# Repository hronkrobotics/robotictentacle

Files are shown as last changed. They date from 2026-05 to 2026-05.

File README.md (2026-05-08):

# robotictentacle

2-DOF robotic tentacle powered by dual 12V geared hobby motors, an L298N motor driver, and an ESP32-C3 Super Mini. Features joystick control and dual 3D-printed capstan drives for tendon actuation. Uses standard thread for proof-of-concept, with support for stronger nylon or cable-based tendons.


## Project Status

This project is currently a **proof of concept**. It demonstrates a low-cost tendon-driven robotic tentacle mechanism using hobby motors, 3D-printed capstan drives, and an ESP32-C3 controller.

The current version is not intended as a finished functional robotic manipulator. The long-term goal is to improve the mechanical design, tendon routing, materials, and control system so the concept can be used in more practical robotic systems, such as:

- Soft robotic grippers
- Tendon-driven manipulators
- Biomimetic robotic arms
- Educational robotics demos
- Low-cost actuation experiments

## System Overview

The tentacle uses a flexible PTFE tube as the central spine. 3D-printed discs are spaced along the tube to create the tentacle body. Threads are routed through aligned holes in the discs and wrapped around two 3D-printed capstans. Each capstan is driven by a 12V geared DC hobby motor.

The motors are controlled by an L298N H-bridge motor driver, which is connected to an ESP32-C3 Super Mini. A joystick provides manual control over the two axes of motion.

## System Breakdown

```mermaid
flowchart TD
    A[12V 3A Power Supply] --> B[L298N Motor Driver]
    B --> C[12V DC Gear Motor 1]
    B --> D[12V DC Gear Motor 2]

    E[ESP32-C3 Super Mini] --> B
    F[Joystick Module] --> E

    C --> G[3D Printed Capstan Drive 1]
    D --> H[3D Printed Capstan Drive 2]

    G --> I[Tendon / Thread Routing]
    H --> I

    I --> J[PTFE Tube Core]
    J --> K[3D Printed Tentacle Discs]
    K --> L[2-DOF Robotic Tentacle]

    M[Wooden Base] --> B
    M --> E
    M --> F
    M --> C
    M --> D
    M --> L
```

## Bill of Materials

| Item | Quantity | Notes |
|---|---:|---|
| ESP32-C3 Super Mini | 1 | Main microcontroller |
| L298N motor driver | 1 | Dual H-bridge motor driver |
| 12V DC geared hobby motors | 2 | Used to drive the capstans |
| 12V 3A power supply | 1 | Main motor power supply |
| Analog joystick module | 1 | Used for manual control |
| Breadboard | 1 | For prototyping connections |
| Jumper wires / hookup wires | As needed | Signal and power wiring |
| Wooden baseboard | 1 | Mounting platform for the full assembly |
| PTFE tube | 1 length | Main flexible core of the tentacle |
| 3D printed tentacle discs | Multiple | Sorted by size and placed along the PTFE tube |
| 3D printed capstan drives | 2 | One for each motion axis |
| Thread | As needed | Proof-of-concept tendon material |
| Needle | 1 | Used to route thread through the discs |
| PLA filament | As needed | Used for 3D printed parts |
| Hot glue or super glue | As needed | Used to secure discs and tendons |
| Solder | As needed | For electrical connections if needed |

## Required Tools

| Tool | Purpose |
|---|---|
| 3D printer | Printing discs, capstans, and mounts |
| Soldering iron | Securing wires and electrical connections |
| Hot glue gun | Attaching parts and securing tendons |
| Screwdriver | Mounting motors and hardware |
| Wire stripper / cutter | Preparing wires |

## 3D Printing Settings

The prototype parts were printed using standard PLA settings.

Recommended starting settings:

| Setting | Value |
|---|---|
| Material | PLA |
| Infill | 25% gyroid |
| Layer height | 0.2 mm |
| Walls | 2-3 |
| Supports | As needed depending on part orientation |

These settings are not strict. The parts do not require extremely high strength, but the capstans and base mounts should be sturdy enough to avoid snapping under tendon tension.

## Mechanical Assembly

### 1. Prepare the Base

Start with a wooden baseboard large enough to hold:

- The two motors
- The L298N motor driver
- The ESP32-C3 Super Mini
- The joystick module
- The breadboard or wiring area
- The tentacle assembly

Mount the two 12V geared DC motors onto the base. Make sure the motor shafts are accessible and aligned with where the capstan drives will sit.

### 2. Prepare the PTFE Core

Cut the PTFE tube to the desired tentacle length. This tube acts as the main flexible spine of the robot.

The PTFE tube is the core of the build. The 3D-printed discs slide onto it, and the tendon threads run along the outside through aligned holes in the discs.

### 3. Sort the Tentacle Discs

Print all tentacle discs and sort them in order of size.

The discs should be installed along the PTFE tube with consistent spacing. A spacing of around **5-10 mm** between discs is recommended.

Smaller spacing can create a more continuous and dexterous tentacle shape, while larger spacing makes assembly easier and reduces the number of printed parts required.

### 4. Install the Discs

Slide the first disc onto the PTFE tube. Add hot glue or super glue around the contact area to secure it in place.

Continue adding discs one by one.

Important: make sure the tendon holes in every disc are aligned. If the holes are not aligned, the tendons will twist or bind later during assembly.

Recommended process:

1. Add one disc to the PTFE tube.
2. Align the four tendon holes.
3. Apply hot glue or super glue.
4. Add the next disc with the same spacing.
5. Repeat until the tentacle body is complete.

### 5. Prepare the Capstan Drives

Print two capstan drives: one for each axis of motion.

Each capstan controls one pair of opposing tendon directions.

For each capstan:

1. Take one end of the thread.
2. Wrap it around one side of the capstan about 5 times.
3. Feed the thread through the center hole or anchor point.
4. Secure it with a knot, hot glue, or both.
5. Repeat for the other side of the capstan if using opposing tendon pulls.

The goal is for the capstan to wind one side of the tendon while releasing the other side.

### 6. Route the Tendons

Use a needle to route the thread through the holes in the tentacle discs.

Route the tendons through the full length of the tentacle and back toward the motor/capstan area.

Tips:

- Route the upper axis first to avoid access issues later.
- Keep the threads as straight as possible.
- Avoid crossing or twisting tendons.
- Make sure each tendon path passes through the matching aligned hole in every disc.
- Leave extra thread length for tensioning and adjustment.

This prototype uses regular thread as a proof of concept. For future versions, the thread can be replaced with stronger materials such as nylon string, braided fishing line, cable, or other tendon materials.

### 7. Mount the Tentacle Assembly

Mount the tentacle base to the wooden board. The tentacle should start upright in its neutral position.

Make sure the tendons can travel freely from the tentacle body to the capstans without rubbing sharply against the base or hardware.

### 8. Mount Electronics

Mount the following onto the wooden baseboard:

- ESP32-C3 Super Mini
- L298N motor driver
- Breadboard
- Joystick module
- Power input wiring

Keep motor power wiring separated from signal wiring where possible to reduce electrical noise.

## Wiring

### L298N to ESP32-C3 Super Mini

| L298N Pin | ESP32-C3 Super Mini Pin | Purpose |
|---|---|---|
| IN1 | GPIO4 | Motor A direction control |
| IN2 | GPIO5 | Motor A direction control |
| IN3 | GPIO6 | Motor B direction control |
| IN4 | GPIO7 | Motor B direction control |
| ENA | GPIO10 | Motor A PWM speed control |
| ENB | GPIO3 | Motor B PWM speed control |
| GND | GND | Common ground |

### Joystick to ESP32-C3 Super Mini

| Joystick Pin | ESP32-C3 Super Mini Pin | Purpose |
|---|---|---|
| VRx | GPIO0 | X-axis analog input |
| VRy | GPIO1 | Y-axis analog input |
| SW | GPIO20 | Joystick button input |
| VCC | 3V3 | Joystick power |
| GND | GND | Ground |

Do not power the joystick from 5V. The ESP32-C3 uses 3.3V logic and its analog inputs should not receive 5V.

### Motors to L298N

| Motor | L298N Output |
|---|---|
| Motor A | OUT1 and OUT2 |
| Motor B | OUT3 and OUT4 |

### Power Wiring

| Power Connection | Destination |
|---|---|
| 12V power supply positive | L298N 12V input |
| 12V power supply negative | L298N GND |
| ESP32-C3 GND | L298N GND |

Use a common ground between the ESP32-C3 and the L298N. The ESP32-C3 can be powered separately over USB during development.

Do not power the ESP32-C3 directly from the L298N 5V output unless the regulator behavior has been verified. Motor drivers can introduce noise and voltage dips that may reset the microcontroller.

## Control Mapping

| Joystick Direction | Tentacle Action |
|---|---|
| Left / Right | Axis 1 movement |
| Forward / Backward | Axis 2 movement |
| Button press | Stop motors |

The current firmware directly maps joystick direction to motor direction. Releasing the joystick stops the motors. There is no closed-loop position control in this proof-of-concept version.

## Example Arduino Pin Definitions

```cpp
// L298N -> ESP32-C3 Super Mini
#define IN1 4
#define IN2 5
#define IN3 6
#define IN4 7
#define ENA 10
#define ENB 3

// Joystick
#define JOY_X 0
#define JOY_Y 1
#define JOY_SW 20
```

## Notes and Limitations

This build is experimental and has several limitations:

- No position feedback
- No encoders
- No force sensing
- No closed-loop control
- Thread can stretch or slip
- Capstan tension may need frequent adjustment
- Motion depends heavily on tendon routing and friction
- The tentacle may not return perfectly to center without mechanical improvements

For better performance, future versions should consider:

- Stronger tendon material
- Improved capstan geometry
- Better tendon tensioning system
- Bearings or low-friction guides
- Encoders for motor feedback
- Limit switches or homing sensors
- Flexible printed body sections
- Silicone or soft robotic segments
- Closed-loop position control

## Future Improvements

Planned or possible improvements include:

- Replacing thread with nylon line or braided cable
- Adding mechanical tensioners
- Designing a more rigid motor mount
- Adding feedback sensors
- Improving the tentacle body geometry
- Testing different disc spacing
- Adding automatic center calibration
- Developing a soft robotic gripper based on the same tendon-driven concept
- Creating a more compact PCB-based control system

## Media

This project was made in collaboration with **Blueprint.am**.

Videos, build footage, and demonstration links can be added here:

- [Video 1](https://www.instagram.com/reel/DXw7M-UJZG7/?utm_source=ig_web_copy_link&igsh=MzRlODBiNWFlZA==)
- [Video 2](https://www.instagram.com/reel/DYAJk1oO_MS/?utm_source=ig_web_copy_link&igsh=MzRlODBiNWFlZA==)

## Disclaimer

This is a proof-of-concept hardware project. Use caution when working with motors, power supplies, soldering tools, and moving mechanical parts. Verify wiring before powering the system, and keep fingers clear of capstans and tendons while the motors are active.

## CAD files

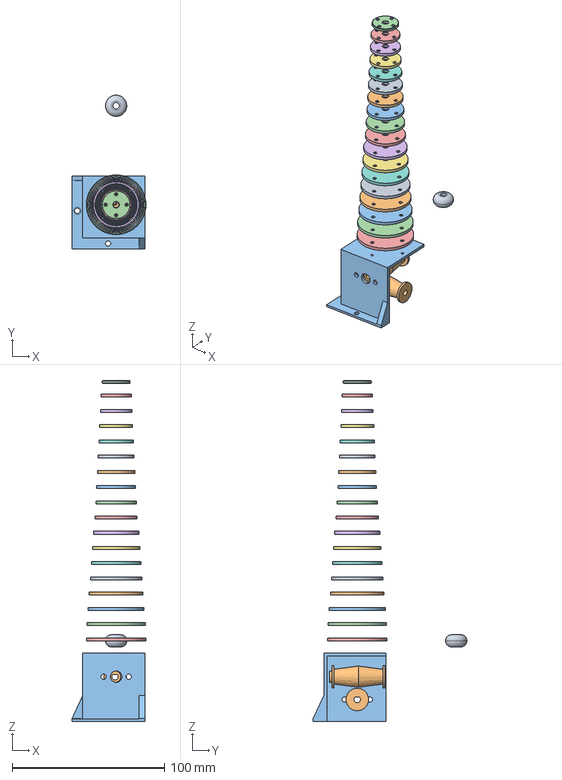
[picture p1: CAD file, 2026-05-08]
Robot Tentacle CAD.step
48.6 x 101.0 x 224.0 mm

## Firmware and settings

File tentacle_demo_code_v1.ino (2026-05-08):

#include "driver/ledc.h"

// ================= UART =================
#define UART_RX 17
#define UART_TX 18
#define BAUDRATE 115200

// ================= SERVO PINS =================
#define BASE_PIN     5      // 360° continuous
#define SHOULDER_PIN 12     // 180°
#define ELBOW1_PIN   13     // 180°
#define ELBOW2_PIN   14     // 180°
#define WRIST_PIN    11     // 180°
#define CLAW_PIN     9      // 180° gripper

// ================= LEDC CONFIG =================
#define SERVO_FREQ_HZ   50
#define SERVO_TIMER     LEDC_TIMER_0
#define SERVO_MODE      LEDC_LOW_SPEED_MODE
#define SERVO_RES       LEDC_TIMER_10_BIT

#define BASE_CH      LEDC_CHANNEL_0
#define SHOULDER_CH  LEDC_CHANNEL_1
#define ELBOW1_CH    LEDC_CHANNEL_2
#define ELBOW2_CH    LEDC_CHANNEL_3
#define WRIST_CH     LEDC_CHANNEL_4
#define CLAW_CH      LEDC_CHANNEL_5

// ================= PWM VALUES (10-bit @ 50 Hz) =================
#define DUTY_MIN     26
#define DUTY_CENTER  77
#define DUTY_MAX     128

// ================= CLAW HARD LIMITS =================
#define CLAW_MIN  30    // adjust as needed
#define CLAW_MAX  95    // adjust as needed

// ================= JOG / STEP CONFIG =================
#define POS_STEP        1
#define BASE_STEP       1
#define STEP_DELAY_MS  50

// ================= STATE =================
int baseDir      = 0;
int shoulderDir  = 0;
int elbow1Dir    = 0;
int elbow2Dir    = 0;
int wristDir     = 0;
int clawDir      = 0;

// Base speed offset (relative to center)
int baseOffset = 0;

// Positional servos
int shoulderPos = DUTY_CENTER;
int elbow1Pos   = DUTY_CENTER;
int elbow2Pos   = DUTY_CENTER;
int wristPos    = DUTY_CENTER;
int clawPos     = DUTY_CENTER;

// ================= COMMAND HANDLER =================
void handleCmd(const String& cmd) {
  Serial.print("RX: ");
  Serial.println(cmd);

  if (cmd == "RB,FWD")      baseDir = +1;
  else if (cmd == "RB,BACK") baseDir = -1;
  else if (cmd == "RB,STOP") baseDir = 0;

  else if (cmd == "SH,FWD")  shoulderDir = +1;
  else if (cmd == "SH,BACK") shoulderDir = -1;
  else if (cmd == "SH,STOP") shoulderDir = 0;

  else if (cmd == "EL1,FWD")  elbow1Dir = +1;
  else if (cmd == "EL1,BACK") elbow1Dir = -1;
  else if (cmd == "EL1,STOP") elbow1Dir = 0;

  else if (cmd == "EL2,FWD")  elbow2Dir = +1;
  else if (cmd == "EL2,BACK") elbow2Dir = -1;
  else if (cmd == "EL2,STOP") elbow2Dir = 0;

  else if (cmd == "WR,FWD")  wristDir = +1;
  else if (cmd == "WR,BACK") wristDir = -1;
  else if (cmd == "WR,STOP") wristDir = 0;

  else if (cmd == "CL,FWD")  clawDir = +1;
  else if (cmd == "CL,BACK") clawDir = -1;
  else if (cmd == "CL,STOP") clawDir = 0;
}

// ================= SETUP =================
void setup() {
  Serial.begin(115200);
  Serial1.begin(BAUDRATE, SERIAL_8N1, UART_RX, UART_TX);

  ledc_timer_config_t timer;
  memset(&timer, 0, sizeof(timer));
  timer.speed_mode       = SERVO_MODE;
  timer.timer_num        = SERVO_TIMER;
  timer.duty_resolution  = SERVO_RES;
  timer.freq_hz          = SERVO_FREQ_HZ;
  timer.clk_cfg          = LEDC_AUTO_CLK;
  ledc_timer_config(&timer);

  ledc_channel_config_t ch;
  memset(&ch, 0, sizeof(ch));
  ch.speed_mode = SERVO_MODE;
  ch.timer_sel  = SERVO_TIMER;
  ch.duty       = DUTY_CENTER;

  ch.channel = BASE_CH;     ch.gpio_num = BASE_PIN;     ledc_channel_config(&ch);
  ch.channel = SHOULDER_CH; ch.gpio_num = SHOULDER_PIN; ledc_channel_config(&ch);
  ch.channel = ELBOW1_CH;   ch.gpio_num = ELBOW1_PIN;   ledc_channel_config(&ch);
  ch.channel = ELBOW2_CH;   ch.gpio_num = ELBOW2_PIN;   ledc_channel_config(&ch);
  ch.channel = WRIST_CH;    ch.gpio_num = WRIST_PIN;    ledc_channel_config(&ch);
  ch.channel = CLAW_CH;     ch.gpio_num = CLAW_PIN;     ledc_channel_config(&ch);

  Serial.println("Slave ready — claw limits enabled");
}

// ================= LOOP =================
void loop() {
  static String buf;
  static unsigned long lastStep = 0;

  while (Serial1.available()) {
    char c = Serial1.read();
    if (c == '\n' || c == '\r') {
      buf.trim();
      if (buf.length()) handleCmd(buf);
      buf = "";
    } else {
      buf += c;
    }
  }

  unsigned long now = millis();
  if (now - lastStep >= STEP_DELAY_MS) {
    lastStep = now;

    if (baseDir != 0) baseOffset += baseDir * BASE_STEP;
    int baseDuty = constrain(DUTY_CENTER + baseOffset, DUTY_MIN, DUTY_MAX);
    ledc_set_duty(SERVO_MODE, BASE_CH, baseDuty);
    ledc_update_duty(SERVO_MODE, BASE_CH);

    if (shoulderDir != 0) shoulderPos += shoulderDir * POS_STEP;
    ledc_set_duty(SERVO_MODE, SHOULDER_CH, shoulderPos);
    ledc_update_duty(SERVO_MODE, SHOULDER_CH);

    if (elbow1Dir != 0) elbow1Pos += elbow1Dir * POS_STEP;
    ledc_set_duty(SERVO_MODE, ELBOW1_CH, elbow1Pos);
    ledc_update_duty(SERVO_MODE, ELBOW1_CH);

    if (elbow2Dir != 0) elbow2Pos += elbow2Dir * POS_STEP;
    ledc_set_duty(SERVO_MODE, ELBOW2_CH, elbow2Pos);
    ledc_update_duty(SERVO_MODE, ELBOW2_CH);

    if (wristDir != 0) wristPos += wristDir * POS_STEP;
    ledc_set_duty(SERVO_MODE, WRIST_CH, wristPos);
    ledc_update_duty(SERVO_MODE, WRIST_CH);

    // ===== CLAW WITH HARD LIMITS ONLY =====
    if (clawDir != 0) {
      clawPos += clawDir * POS_STEP;
      clawPos = constrain(clawPos, CLAW_MIN, CLAW_MAX);
    }
    ledc_set_duty(SERVO_MODE, CLAW_CH, clawPos);
    ledc_update_duty(SERVO_MODE, CLAW_CH);
  }
}
